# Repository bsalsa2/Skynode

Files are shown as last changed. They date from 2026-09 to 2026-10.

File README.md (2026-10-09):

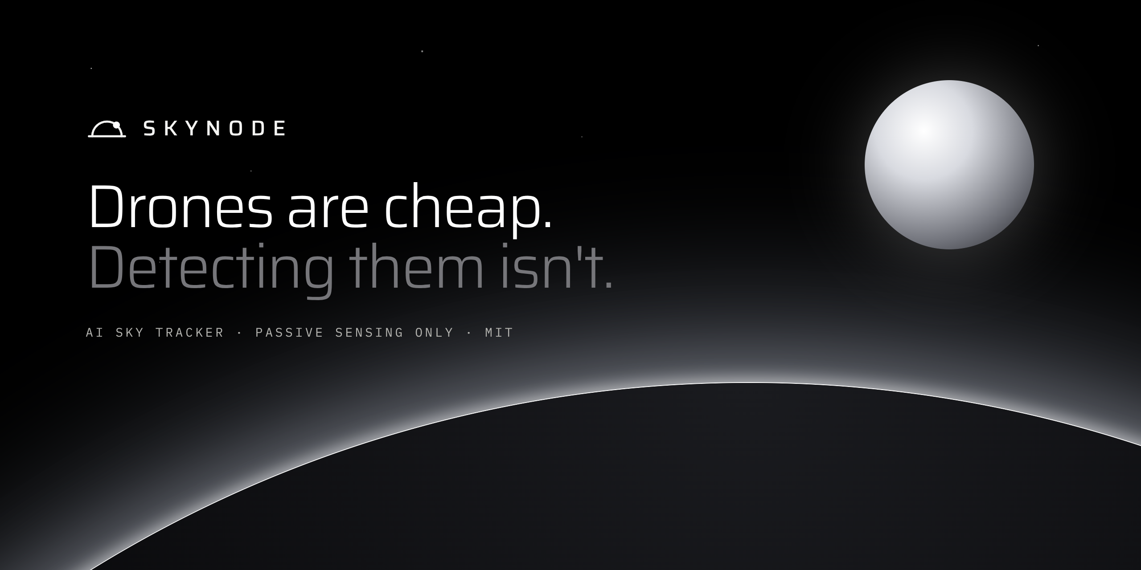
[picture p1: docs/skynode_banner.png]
Skynode: Drones are cheap. Detecting them isn't.


# Skynode

  

**Website: [skynode-si.netlify.app](https://skynode-si.netlify.app)** (source in [`web/`](web/))

**A low-cost visual sensing platform, starting with one passive sky-tracking node.**

A webcam on a pan-tilt mount watches the sky, a YOLO model finds aircraft and birds in each frame, the mount turns to follow the target, and every sighting is logged. This is Phase 1: one node, mostly tested in simulation so far. The physical unit is not built yet.

> **Scope:** passive sensing and tracking only. No payloads, no effectors, and nothing that interacts with or interferes with aircraft. No jamming, no spoofing, and no transmitting on aviation or drone-control frequencies. Ordinary Wi-Fi and USB networking between Skynode's own parts is fine.

## Status

| Part | Status | Notes |
|---|---|---|
| Pico servo firmware (smooth motion, calibration, command protocol) | Tested in software | Not yet run on the physical servos |
| Detection and tracking loop | Simulated | Runs on recorded video and a webcam; covered by the test suite |
| Pan-tilt control | Simulated | Sends commands to the Pico over Wi-Fi or USB |
| Sighting logger | Simulated | Built and tested; not yet run on the real hardware |
| Live dashboard | Simulated | Built and tested; not yet run on the real hardware |
| Pan-tilt mount (CAD) | Designed | STEP and STL files included; not printed |
| Wiring and bill of materials | Designed | Breadboard prototype plan; not wired |
| Detection model v2 | Tested on video | 43 real-world clips (see Results) |
| Detection model v3 (drone and aircraft classes) | In training | Not yet scored |
| Physical build | **Not built yet** | Nothing has run on real hardware |
| Accuracy against ADS-B flight data | Written, not yet run | Logger and comparison tool exist; tested only on made-up data. No results yet |

## How it works

```mermaid
flowchart LR
    CAM[Webcam] -->|frames| DET[Detection<br/>YOLOv8n · ONNX]
    DET -->|boxes| TRK[Tracking<br/>pick one target]
    TRK -->|pixel error| CTL[Pan-tilt control<br/>proportional]
    CTL -->|P92.5 T47.0<br/>Wi-Fi or USB| PICO[Pico WH<br/>servo firmware]
    PICO -->|PWM| SERVOS[Pan + tilt<br/>servos]
    SERVOS -.->|camera moves| CAM
    DET --> LOG[(Sighting logger)]
    TRK --> LOG
    LOG --> DASH[Live dashboard]
```

1. **Detection.** The brain (a laptop for now, a Raspberry Pi 4 later) grabs webcam frames and runs a YOLO model through ONNX Runtime. It runs a custom two-class model (`drone` and `aircraft`). See [Model](#model).
2. **Tracking.** It picks one target and measures how far that target sits from the center of the frame, in pixels.
3. **Pan-tilt control.** A proportional controller turns the pixel error into a small correction ("the target is 40 px right, so pan +2°").
4. **Actuation.** The brain sends a plain-text command like `P92.5 T47.0` to the Pico over Wi-Fi (UDP) or USB serial. The Pico moves both servos smoothly and keeps them inside safe angle limits.
5. **Logging.** Each sighting is recorded with time, class, confidence, pan and tilt angle, and a snapshot. A live dashboard shows the camera, the boxes, and the log as it grows. See [Live dashboard](brain/README.md#live-dashboard).

Detection, tracking, and control are separate modules, so each layer can be reused on future platforms.

## Quickstart

Software only. You can run detection on a webcam or video file without the Pico.

```bash
pip install -r brain/requirements.txt opencv-python-headless onnx pyyaml
python -m unittest discover tests -v      # hardware-dependent tests skip with a stated reason
```

Then follow [`brain/README.md`](brain/README.md) to export the YOLOv8n model once and run the brain.

No hardware? `python -m brain.demo <folder of test videos> --model <model.onnx>` runs detection, the logger and the dashboard on your own videos. See [Demo mode](brain/README.md#demo-mode-your-own-test-videos). For the Pico, see [`pico/README.md`](pico/README.md).

## Results so far

All numbers here come from the repo. Nothing has been measured on the physical node.

**Detection model v2**, tested on **43 real-world videos** of planes, military jets, and drones:

- On real aircraft, v2 wrongly called **7.5% of frames** a drone (**798 of 10,657** frames).
- That was **0.8%** for civilian planes and **10.8%** for military jets (mostly distant F-35s).

**Model v3** (merged classes `drone` and `aircraft`, 960 px input, resumed from v2) is in training. Next step: score it against the same 43 clips.

Training used YOLOv8n on a 28,526-image aircraft and drone dataset. See [Training](training/README.md).

## Known limits

- **Range (estimate, not yet measured).** A wide-lens webcam detects small drones only at short range, likely tens of meters. Aircraft are detectable much farther.
- **Conditions.** Visual sensing is weaker in darkness, fog, and rain.
- **Not a replacement for Remote ID or RF sensors.** It can see drones that broadcast nothing, which Remote ID can't, but it doesn't replace either.
- **Hardware not built.** Nothing has run on the physical servos, camera mount, or Pico yet. Anything marked "simulated" has only been tested in software.

## Repo layout

```
skynode/
├── pico/       MicroPython servo firmware (runs on the Pico WH)
├── brain/      detection, tracking, control, logging (runs on laptop / Pi 4)
├── hardware/   3D-print files for the pan-tilt mount
├── training/   Colab training notebook and dataset scripts
├── web/        project website
├── docs/       wiring diagram, banner, renders
└── tests/      laptop-side tests
```

## Model

Model files are **not** in git (`*.onnx` and `*.pt` are gitignored).

- **Current model: a custom two-class YOLOv8n**, with classes `drone` and `aircraft`. It was built by merging the labels of a source dataset of **28,526 labeled images** into those two classes. Its first version is **v2** (results above).
- **v3** (`drone` and `aircraft`, 960 px input, resumed from v2) is **in training**. It has not been scored yet.
- The model path and target classes are settings in `brain/config.toml`, so a new model drops in without code changes.
- See [Training](training/README.md) for how models are made. Finished models go on [GitHub Releases](https://github.com/bsalsa2/Skynode/releases).

## Bill of materials

Also in [`bom.csv`](bom.csv). Costs are rough USD estimates for the whole line (both servos in the servo row), before shipping.

| Part | Qty | Purpose | Est. cost | Link |
|---|---|---|---|---|
| Raspberry Pi Pico WH | 1 | Servo controller + Wi-Fi link (already owned) | owned | [link](https://www.raspberrypi.com/products/raspberry-pi-pico/) |
| Breadboard | 1 | Power rails and signal wiring (already owned) | owned | |
| SG90 micro servo (or SG92R) | 2 | Pan and tilt axes | $11.90 | [link](https://www.adafruit.com/product/169) |
| SG90 pan-tilt bracket (or print `hardware/pantilt.scad`) | 1 | Holds both servos and the camera | $8.95 | [link](https://www.adafruit.com/product/1968) |
| 1080p USB webcam | 1 | The camera that watches the sky | $70.00 | [link](https://www.logitech.com/en-us/shop/p/c920s-pro-hd-webcam) |
| 5V 2A USB power supply | 1 | Dedicated servo power | $7.95 | [link](https://www.adafruit.com/product/1994) |
| USB breakout board | 1 | Brings the supply's 5V and GND onto the breadboard rails | $1.50 | [link](https://www.adafruit.com/product/1833) |
| 470–1000 µF 16V+ electrolytic capacitor | 1 | Absorbs servo current spikes across the servo power rails | $0.95 | [link](https://www.sparkfun.com/electrolytic-decoupling-capacitors-1000uf-25v.html) |
| Jumper wires (male/male) | 1 | Breadboard and servo connections | $3.95 | [link](https://www.adafruit.com/product/758) |
| M2/M3 screw assortment | 1 | Servo tabs and horns (M2), tilt pivot and base mounting (M3) | $8.00 | |
| Computer that runs the model | 1 | Laptop now, Raspberry Pi 4 later (not in the total) | not included | |
| **Total to buy** | | | **$113.20** | |

About $113 in new parts for the sensing hardware (camera, servos, mount, power), before the computer that runs the model. The total leaves out the Pico WH and breadboard (already owned) and the computer.

## Wiring

Skynode wiring diagram

SG90 wire colors: **brown = GND**, **red = +5 V**, **orange = signal**.

| From | To |
|---|---|
| 5 V 2 A supply → USB breakout VBUS | breadboard + rail |
| USB breakout GND | breadboard − rail |
| Both servo reds | + rail |
| Both servo browns | − rail |
| Pan servo orange | Pico pin 1 (GP0) |
| Tilt servo orange | Pico pin 2 (GP1) |
| Pico pin 3 (GND) | − rail (common ground) |
| 470–1000 µF capacitor | across + and − rails, stripe to − |
| Pico micro-USB | laptop (USB link) or any phone charger (Wi-Fi link) |

**Power notes**

- The servos get their own 5 V 2 A supply, so a stalling servo can't brown out the Pico. Don't also connect Pico VBUS (pin 40) to the + rail, or two supplies will fight.
- The common ground wire is required: servo signals are measured against GND.

## Pan-tilt mount

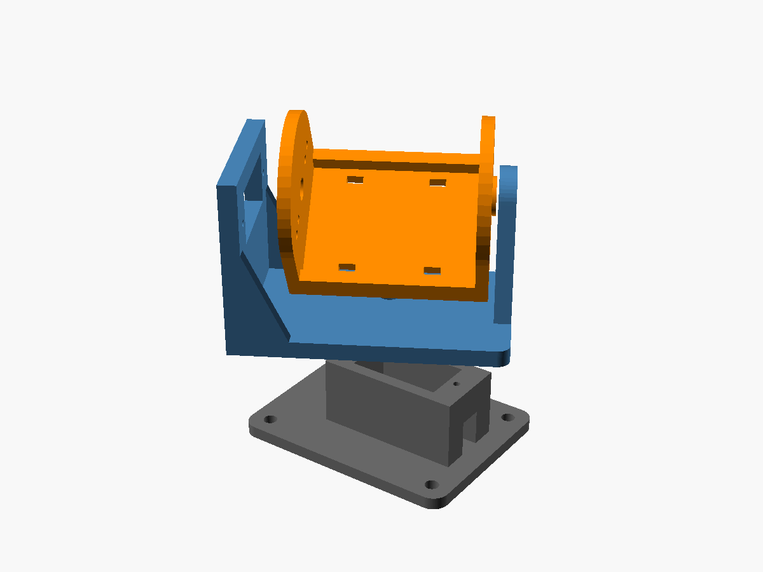
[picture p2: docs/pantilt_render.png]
Pan-tilt mount render


[`hardware/pantilt.py`](hardware/pantilt.py) is a parametric CadQuery design: servo size, horn, webcam size, and wall thickness are parameters at the top of the file. Each part has an editable STEP file and a print-ready STL. It prints as three parts without supports:

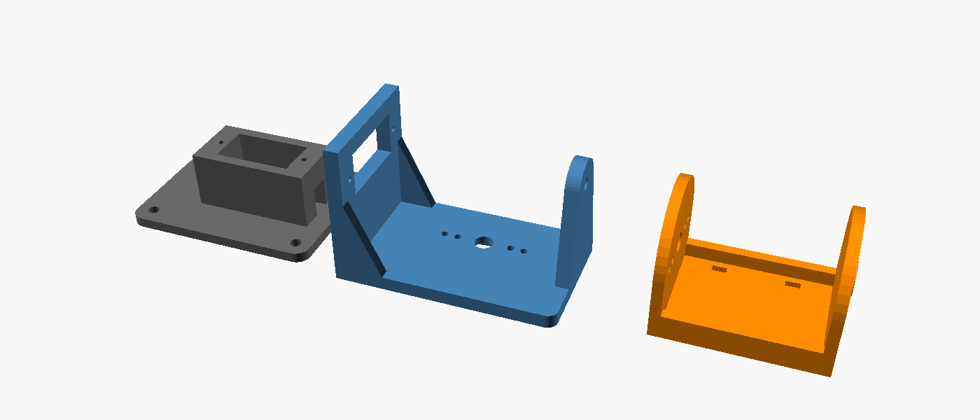
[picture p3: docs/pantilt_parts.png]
The three printed parts


| File | Part |
|---|---|
| [`pantilt_base.step`](hardware/pantilt_base.step) · [`.stl`](hardware/pantilt_base.stl) | Holds the pan servo; screws down with 4× M3 |
| [`pantilt_yoke.step`](hardware/pantilt_yoke.step) · [`.stl`](hardware/pantilt_yoke.stl) | Sits on the pan horn; holds the tilt servo and the M3 pivot |
| [`pantilt_camera_arm.step`](hardware/pantilt_camera_arm.step) · [`.stl`](hardware/pantilt_camera_arm.stl) | Webcam cradle on the tilt horn; camera held with two zip ties |

Measure your servo and camera and adjust the parameters before printing. See [`hardware/README.md`](hardware/README.md).

## Roadmap

**Vision.** Phase 1 is one passive sky-tracking node. The long-term goal is autonomy for missile and drone detection and defense systems. Open work is tracked as [GitHub issues](https://github.com/bsalsa2/Skynode/issues) under the *Phase 1: one working node* milestone.

- [x] Pico servo firmware: smooth motion, calibration, command protocol (tested in software)
- [x] Detection and tracking loop, working in simulation, covered by automated tests
- [x] Pan-tilt mount designed in CAD, with STEP and STL files
- [x] Wiring diagram and bill of materials
- [ ] Detection model training: v3 with drone and aircraft classes (in training, not yet scored)
- [ ] Sighting logger (built and tested in simulation; not yet run on real hardware)
- [ ] Live dashboard (built and tested in simulation; not yet run on real hardware)
- [ ] Build the physical hardware
- [ ] Outdoor test
- [ ] Test against real flight data (ADS-B) and publish accuracy results
- [ ] Pi 4 + solar deployment

**Nothing has run on real hardware yet.** Every item marked as simulated or software-tested has only been checked on a computer.

The website's Status section lists these same items. Update both together.

## Built with Claude Code

Claude Code (Anthropic's coding agent) helped write much of the code, tests, and documentation here. Every change is in the git history.

## License

MIT, see [LICENSE](LICENSE).

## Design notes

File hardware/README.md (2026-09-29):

# hardware/

Parametric pan-tilt mount for two SG90 servos and a small USB webcam.

**Source of truth: [`pantilt.py`](pantilt.py) (CadQuery).** It builds every printed part as an editable STEP file plus an STL. [`pantilt.scad`](pantilt.scad) is the original OpenSCAD version, kept for reference: same parameters and identical geometry, but edit the CadQuery script first, and copy any change to the SCAD file only if you still use it.

| File | What it is |
|---|---|
| `pantilt.py` | The design (CadQuery). All dimensions are parameters at the top |
| `pantilt.scad` | Original OpenSCAD version (reference only) |
| `pantilt_base.step` / `.stl` | Base: holds the pan servo (shaft up) and screws down with 4× M3 |
| `pantilt_yoke.step` / `.stl` | Yoke: sits on the pan horn, holds the tilt servo, carries the M3 pivot |
| `pantilt_camera_arm.step` / `.stl` | Camera arm: webcam cradle on the tilt horn and pivot. Strap the camera with two zip ties |

A two-axis mount needs three moving links (fixed, panning, tilting), so it prints as three parts.

## Before printing

Measure your servo and camera with calipers and edit the parameters: `servo_l/w/h`, `tab_z`, `horn_seat_z`, the horn sizes, and `cam_w/h/d`. Then rebuild all STEP and STL files from the repo root:

```
pip install cadquery
python hardware/pantilt.py
```

The STEP files open in FreeCAD, Fusion 360, Onshape, or SolidWorks for further editing.

Print in PLA or PETG, 0.2 mm layers, 3 walls, 25–40 % infill, no supports. The parts are already oriented flat side down.

## Assembly

1. **Base:** drop the pan servo into the base, with its lead through a cable slot, and screw the tabs down (M2 self-tapping; SG90s come with these).
2. **Yoke:** press a double-arm horn into the recess under the yoke and fix it with two M2 screws from the top. Center the pan servo (`HOME`, 90°), set the yoke facing forward, press the horn onto the spline, and drive the horn screw through the center hole.
3. **Tilt servo:** push it through the yoke's window from the outside, shaft pointing in, and screw its tabs to the upright.
4. **Camera arm:** fix a horn into the left cheek's recess, put the arm between the uprights, press the horn onto the tilt servo (servo at its level angle), and add the horn screw. On the other side, an M3 × 12 screw with a washer goes through the yoke's pivot hole into the arm.
5. Zip-tie the webcam into the cradle, lens forward.

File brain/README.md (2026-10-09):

# brain/

Runs on the laptop now and on a Raspberry Pi 4 later. Every camera frame goes through four steps: **detect → track → control → send**.

| Module | Job |
|---|---|
| `detector.py` | Runs a YOLO model (ONNX) on a frame and returns detections: class, confidence, box |
| `tracker.py` | Picks one target and stays locked on it from frame to frame |
| `controller.py` | Proportional control: how far off-center the target is → new pan/tilt angles |
| `link.py` | Talks to the Pico over Wi-Fi (UDP), USB serial, or not at all |
| `overlay.py` | Draws boxes and status on the preview window |
| `logger.py` | Logs every sighting (plus an hourly "sky clear" check) to `logs/`, with a snapshot of its best moment |
| `dashboard.py` | The live dashboard: a small web server inside the brain, for your browser |
| `dashboard/` | The dashboard page itself: HTML, CSS, JavaScript and fonts, all served locally |
| `config.py` + `config.toml` | Settings: defaults in code, your changes in the TOML file |
| `run.py` | The main loop that wires it all together |

An ADS-B logger and comparison tool are written (see "Compare with real flights" below) but have not yet been run against a real feed.

## Setup

You need Python **3.11 or newer**. From the repo root:

```
python -m venv .venv
.venv\Scripts\activate            # Windows
source .venv/bin/activate         # Mac / Linux
pip install -r brain/requirements.txt
```

## Get a model

Start with the pretrained **YOLOv8n** COCO model. It has 80 everyday classes, including `airplane` and `bird`. Export it to ONNX once:

**Option A: Google Colab** (nothing to install locally). In a new notebook, run:

```
!pip install ultralytics
!yolo export model=yolov8n.pt format=onnx
from google.colab import files; files.download("yolov8n.onnx")
```

**Option B: locally**, with `pip install ultralytics` and then `yolo export model=yolov8n.pt format=onnx`. Ultralytics pulls in PyTorch, which is a big download, and you only need it for this one step.

Save the file as **`brain/models/yolov8n.onnx`**. YOLO11 and YOLO26 exports work too (`model=yolo11n.pt`); just change `path` in `config.toml`.

## Run it

### 1. Detection only, no Pico needed

```
python -m brain.run
```

A preview window opens with the webcam. Hold up your phone showing a photo of an airplane or a bird. Target-class detections get a **yellow** box, and the locked target turns **green**. Press `q` to quit. To test on footage instead, use `--source planes.mp4`.

While it runs, open **http://localhost:8080/** in your browser for the [live dashboard](#live-dashboard).

### 2. With the Pico

- **Wi-Fi:** set up the Pico's Wi-Fi (see [`pico/README.md`](../pico/README.md#5-wi-fi-optional)), then run `python -m brain.run --link wifi`. The brain finds the Pico automatically. To make Wi-Fi the default, set `type = "wifi"` under `[link]` in `config.toml`.
- **USB:** close Thonny, then run `python -m brain.run --link usb`.

When it connects, the brain reads the Pico's angle limits, home, and current position. That way both sides agree on where the camera is pointing.

### 3. First aiming test

1. With the camera on the pan-tilt mount, hold the airplane photo off to the **right** of the camera's view. The camera should turn right, toward it, and settle with the target near the center cross.
2. If it turns **away**, flip `pan_sign` in `config.toml` (`-1` ↔ `1`). Test tilt the same way, holding the photo above the camera and flipping `tilt_sign` if needed.
3. If it overshoots and wobbles, lower `gain` (try 0.2). If it's sluggish, raise `gain` (up to about 0.5) or raise `SPEED` on the Pico.
4. Set `hfov_deg` to your webcam's field of view, so that "20 pixels off-center" turns into the right number of degrees.

## Live dashboard

While the brain runs, open **http://localhost:8080/** in a browser on the same computer. The brain prints the address when it starts:

```
Logging sightings to C:\Users\you\Skynode\logs
Dashboard: http://localhost:8080/
```

The page comes from the brain itself: no internet, no cloud, no account. It has four tabs:

- **Overview:** the live camera with a box around everything the model sees (the locked target gets a solid label), plus pan, tilt and frames per second. Next to it: sightings, drones and aircraft over the last 24 hours, the most recent sightings, and a chart of sightings by hour.
- **Sightings:** the whole log as cards with snapshots. Filter by time (24 hours, 7 days, all) and category (drone, aircraft, other, sky checks). Click a sighting to see all its details.
- **Nodes:** this node's status: online or offline, uptime, how much of that time the camera was actually watching, and which model, camera and link it uses.
- **Settings:** the settings the brain is running with, read-only. To change them, edit `config.toml` and restart the brain.

The dashboard's settings are under `[dashboard]` in `config.toml`. For one run on another port: `python -m brain.run --port 8081`. Without the dashboard: `--no-dashboard` (or `enabled = false`). The logger keeps working either way.

### Demo mode: your own test videos

No Pico, no camera, no real node yet? Run the whole thing (detector, tracker, logger and dashboard) on a folder of videos:

```
python -m brain.demo C:\Users\you\skynode-videos --model models\your-model.onnx --classes drone,aircraft
```

Then open the dashboard as usual. The videos play one after another, in file-name order, and everything on the dashboard comes from this run:

- It's the same code as `python -m brain.run`. Only the camera is different.
- The dashboard says **DEMO · TEST VIDEOS** at the top, because it isn't a live camera.
- There's no Pico, so **pan and tilt are simulated** from where the target is in the picture: the angles the camera *would* point at to center it.
- It logs to `logs/demo/`, apart from your real log, and **starts that log afresh every time**. Add `--keep-logs` to keep the last demo's sightings.
- Time in the demo is the video's time. A 4-second clip is a 4-second sighting, even with `--fast`.

Options: `--classes` (the model's class names to track, like `drone,aircraft`; the default is `target_classes` in `config.toml`), `--fast` (don't wait for each video's own speed), `--loop` (play the folder again and again), `--port`, `--show` (also open the preview window), and `--exit-when-done` (quit after one pass instead of keeping the dashboard open).

**Keep the videos outside the repo folder.** They're never copied or changed, and the demo refuses a folder inside the repo that git doesn't ignore, so they can't be committed by accident. (`demo_videos/`, `test_videos/` and `videos/` in the repo folder are ignored.) The demo only looks at video files directly in the folder you give it (`.mp4 .mov .m4v .avi .mkv .webm`), not in sub-folders.

### What counts as a sighting

A sighting is one continuous lock: from the frame the tracker locks on to the frame it gives up (after `max_missed_frames` frames without seeing the target). Locks shorter than `min_duration_s` (half a second) are most likely the detector blinking, so they aren't logged. For each sighting the log keeps when it started and ended, what the model called it, its best confidence, where the camera pointed at that best moment, and a snapshot of that frame. The terminal shows each one as it's saved:

```
LOGGED airplane 4.2s peak 0.91
```

The model's class decides the category: names in `drone_classes` are **drone**, names in `aircraft_classes` are **aircraft**, and anything else is **other**. With the COCO model that means `bird` sightings are filed under *other*, even though small drones often show up as birds. A custom drone model fixes that.

While nothing is being tracked, the logger also writes a **sky check** once an hour, on the hour (`heartbeat_min = 60`). It proves the node was watching and saw nothing, so a gap in the log means "the brain wasn't running", not "empty sky".

### Where the logs go

```
logs/skynode.db                          every sighting and sky check (SQLite)
logs/snapshots/20261007-140217-001.jpg   the best frame of that sighting
```

`logs/` sits in the repo folder, and git ignores it, so your sightings never end up on GitHub. `skynode.db` is one ordinary SQLite file, and each record is committed the moment a sighting ends, so a crash or a power cut loses nothing that was already logged. The dashboard shows the last 7 days; older sightings stay in the database. To start fresh, delete the folder while the brain isn't running.

To look at it yourself, open it with any SQLite tool (DB Browser for SQLite, or `sqlite3 logs/skynode.db`). One row per sighting or sky check, in a table called `sightings`; `started` and `ended` are unix times in seconds:

```
sqlite3 logs/skynode.db "SELECT id, category, class_name, confidence FROM sightings WHERE kind = 'sighting' ORDER BY started DESC LIMIT 5"
```

Earlier versions wrote one `sightings-YYYY-MM-DD.jsonl` file per day. If you have those, they're imported into the database the first time you start the brain, then renamed to `.jsonl.imported`.

### Export a spreadsheet (to compare with ADS-B)

On the **Sightings** tab, pick a time range and a category, then click **Export CSV**. You get `skynode-sightings.csv`, one row per sighting, newest first:

```
id,kind,category,class_name,start_iso,end_iso,duration_s,confidence,pan,tilt,frames,snapshot
```

`start_iso` and `end_iso` are your local time with its offset from UTC, like `2026-10-07T14:02:17+02:00`. ADS-B flight data is usually in UTC, and the offset makes the conversion exact. Line the times up, then use `pan` and `tilt` to check that the aircraft was where the camera pointed. The export covers what the dashboard shows (the last 7 days, up to 10,000 rows); for anything older, query `logs/skynode.db`.

### Compare with real flights (ADS-B)

Planes broadcast their position, and free public feeds (adsb.lol, airplanes.live) share it with no account. The feeds only show what is flying *now*, so a small logger has to run next to the brain and write it down:

```
python -m brain.adsb             # leave it running while the brain runs
python -m brain.adsb_compare     # afterwards: which sightings does the flight record explain?
```

**Tell it where the camera is, without putting your home on GitHub.** Set `SKYNODE_LAT`, `SKYNODE_LON` (and optionally `SKYNODE_ALT_M`), or create `brain/location.local.toml` with `lat = ...`, `lon = ...`, `alt_m = ...`. Git ignores that file, and the location is never read from `config.toml`. By default the request to the feed uses your position rounded to about 1 km, with a slightly larger radius, and the exact distances are worked out on your computer. Add `--exact` to send the precise position instead.

It writes `logs/adsb_log.csv` (every aircraft within 25 km, with its azimuth and elevation in your sky) and `logs/adsb_polls.csv` (each time the feed answered). The second file is what tells "no aircraft overhead" from "the logger wasn't running". Those sightings are reported as `no_data` and left out of every percentage.

`adsb_compare` reports how many aircraft sightings had a real flight nearby, and how many drone sightings did (possible misclassifications). Two honest limits: it means an aircraft was *nearby*, not that the camera was pointed at it, and planes without a transponder, such as gliders and most drones, never show up. It measures agreement with the public flight record, not accuracy. Treat each mismatch as a lead to check in the snapshot.

### Open it from your phone

By default only the computer running the brain can open the dashboard. To open it from a phone or another laptop on the same Wi-Fi:

1. Set `host = "0.0.0.0"` under `[dashboard]` in `config.toml`, then restart the brain.
2. Find the computer's IP address. Windows: run `ipconfig` and look for *IPv4 Address*. Mac: System Settings → Wi-Fi → Details. Linux or the Pi: `hostname -I`.
3. On the phone, open `http://<that address>:8080/`, for example `http://192.168.1.42:8080/`.

> **Privacy warning:** with `host = "0.0.0.0"`, **anyone on the same network can open the dashboard and watch your camera. There is no password.** Only do this on your own home network, never on school, café or other public Wi-Fi, and set it back to `"127.0.0.1"` when you're done. Point the camera at the sky, not at the neighbours' windows.

On Windows, the firewall may block the phone. Allow Python through it for **Private** networks, the same as for the Pico's Wi-Fi link.

Other web sites can't use the dashboard, even while you have it open. A page somewhere else can't show your camera inside itself, peek at your snapshots, or take up the live stream's places (there are 4). The brain only answers the dashboard's own page, an address you type in or bookmark, and plain links to its front page.

### Try it in the cloud (GitHub Codespaces)

No install and nothing stored on your own computer. A Codespace is a computer GitHub runs for you, and the dashboard opens in a browser tab. It uses a video file as the camera (a cloud computer has no webcam).

1. Download two files to your device: the model `skynode-v3-<date>.onnx` (from Drive ▸ skynode ▸ models) and one short video of a plane or drone.
2. On github.com open the repo, use the branch menu to pick the branch you want, then **Code ▸ Codespaces ▸ Create codespace**. Wait about 2 minutes: `.devcontainer/devcontainer.json` installs the packages for you.
3. In the file list on the left, drag the `.onnx` into `brain/models/` and the video into the top folder (call it `clip.mp4`).
4. Open the terminal (Terminal ▸ New Terminal) and run:
   ```
   python -m brain.run --config brain/config.v3.toml --source clip.mp4 --loop
   ```
   If your model file has a different name, edit `path` in `brain/config.v3.toml`.
5. When it prints `In GitHub Codespaces, open https://...`, click that link (or open the **Ports** tab and click the globe next to port 8080).
6. Press Ctrl+C in the terminal to stop. **Stop the Codespace** when you're done (github.com/codespaces ▸ the `...` menu ▸ Stop). It also stops itself after a while, and the free monthly allowance is limited.

How it stays safe: the dashboard answers only your own Codespace's address, not the rest of `app.github.dev`. Codespaces ports are private (you must be signed in to GitHub) unless you change them to Public, so **don't make port 8080 public**.

Not verified: the live camera picture goes through GitHub's proxy, and I couldn't test how it handles a continuous stream. If the picture stalls, the stat tiles, sightings and chart still work.

## Swap in your own model

No local GPU? Train in Google Colab with phone videos: see [`training/`](../training/README.md).

1. Train with Ultralytics (YOLOv8, YOLO11, or YOLO26), then export: `yolo export model=best.pt format=onnx`.
2. Copy the `.onnx` file into `brain/models/` and update `config.toml`:
   ```toml
   [model]
   path = "models/skynode-drone.onnx"
   target_classes = ["drone", "airplane", "helicopter"]
   ```
3. That's it. The class names are stored inside the `.onnx` file. If a target class isn't in the model, the brain stops and lists the classes the model does know.

Exports made with `nms=True` work too.

## What to expect from the COCO model

- **COCO has no `drone` or `helicopter` class.** Small drones tend to show up as `bird` (sometimes `airplane` or `kite`), which is why `bird` is a default target. It's also the main reason to train your own model.
- **Real birds will trigger it too.** That's the cost of using a stand-in class.
- **Small targets are hard.** A distant aircraft may be only a few pixels wide once the frame is shrunk to 640 × 640. A narrower camera lens (zoom) gains more range than a bigger model does.
- **On a Pi 4**, export with `imgsz=320`. That's roughly 4× faster than 640, at the cost of detection range.

## License note

Ultralytics YOLO weights and anything exported from them are licensed **AGPL-3.0**. Skynode's code never imports Ultralytics (it runs the exported file with ONNX Runtime), but the model file itself comes under Ultralytics' license. That's fine for a personal or open-source project. For a commercial product, plan on either an Ultralytics Enterprise license or training an Apache-2.0 detector (such as YOLOX or RT-DETR) on your own dataset.

## Troubleshooting

| Message or symptom | Fix |
|---|---|
| `No Pico answered on UDP port 5005` | Make sure the Pico shows `WIFI up` and is on the same network. On Windows, allow Python through the firewall for **Private** networks and set your Wi-Fi's network profile to Private. Or set `wifi_host` to the IP address the Pico printed |
| `No Pico found on USB` | Some USB cables only carry power; use a data cable |
| `Can't open COM…` / `/dev/ttyACM0` | Thonny is holding the port; close it |
| `Can't open camera` | Another app (Zoom, Teams, …) has the webcam. For a second camera, use `source = 1` |
| Camera swings away from the target | Flip `pan_sign` or `tilt_sign` |
| Camera wobbles around the target | Lower `gain` |
| `Target class(es) … aren't in this model` | Check the spelling. The message lists every class the model knows |
| Pan/tilt run to their limits when testing on a video file | Expected: a video can't move, so the target never gets centered |
| `WARN the dashboard can't start on 127.0.0.1:8080` | Another program (or a second copy of the brain) is using port 8080. Run with `--port 8081`, or change `port` in `config.toml`. Tracking and logging keep going without the dashboard |
| The dashboard says OFFLINE | The brain isn't running, or the camera stopped sending frames. Check the terminal |
| The phone can't open the dashboard | Set `host = "0.0.0.0"`, use the computer's IP address (not `localhost`), and stay on the same Wi-Fi. On Windows, allow Python through the firewall for Private networks |
| `403`: *Open the dashboard by this computer's address* | You opened it by a name with a real domain, like a custom DNS name `skynode.example.com`. To block a trick called DNS rebinding, the dashboard only answers to `localhost`, an IP address (`http://192.168.1.42:8080/`), the computer's plain name (`raspberrypi`) or a home-network name like `raspberrypi.local`. Use one of those, or list the one exact name you trust in `allowed_hosts` in `config.toml` (GitHub Codespaces addresses are added for you) |
| `403`: *Only the dashboard's own page can load this* | Another web site (or another app on this computer) tried to load the camera or the log. That's blocked on purpose. Open the dashboard itself, e.g. `http://localhost:8080/` |

## Tests

```
python -m unittest discover tests
```

The detector tests build tiny fake models, which needs one extra package: `pip install onnx`. Without it they're skipped. The demo tests make their own tiny videos, and need numpy, OpenCV and onnxruntime (the same as running the brain).

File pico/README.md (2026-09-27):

# pico/: servo firmware

MicroPython firmware for the Raspberry Pi Pico WH. It listens for text commands over USB serial and, optionally, Wi-Fi, and drives the **pan (GP0)** and **tilt (GP1)** servos. Motion is smooth and speed-limited, and angles stay inside calibrated limits.

| File | Job |
|---|---|
| `main.py` | Entry point, runs at power-up. A 50 Hz loop: read USB and Wi-Fi, run commands, step servos |
| `pantilt.py` | The two-servo mount: runs commands, loads/saves `config.json` |
| `servo.py` | One servo: pulse calibration, angle limits, smooth motion |
| `protocol.py` | Parses command text. No hardware code, so it runs on a laptop too |
| `wifi.py` | Optional Wi-Fi link: joins your network, receives commands over UDP |
| `wifi_secrets_example.py` | Template for `wifi_secrets.py` (your network name and password) |

## 1. Flash MicroPython (once)

1. Download the latest **Pico W** `.uf2` from <https://micropython.org/download/RPI_PICO_W/>. The WH is a Pico W with headers, so it takes the same firmware. Any version from 1.20 on works.
2. Hold the **BOOTSEL** button, plug the Pico into USB, then release. A drive called `RPI-RP2` appears.
3. Drag the `.uf2` onto that drive. The Pico reboots into MicroPython.

Any laptop works for this. If your main laptop's USB ports are unreliable, do it from the second one.

## 2. Copy the firmware onto the Pico

**Thonny:** in the bottom-right corner, pick *MicroPython (Raspberry Pi Pico)*. Open `servo.py`, `protocol.py`, `pantilt.py`, `wifi.py`, and `main.py`, choose *File → Save as… → Raspberry Pi Pico*, and keep the same name. Save `main.py` last.

**Or from the command line** (from the repo root):

```
pip install mpremote
mpremote cp pico/servo.py pico/protocol.py pico/pantilt.py pico/wifi.py pico/main.py :
mpremote reset
```

## 3. Test it

Wire the servos first (see the [top-level README](../README.md#wiring)). In Thonny, open `main.py` **from the Pico** and press Run (F5). The Shell prints `READY skynode-pico`. Then type:

```
?              → POS P90.0 T45.0
P0             pan swings to 0°
P180           …and across to 180°
T90            tilt to 90°
P90 T45        both at once
SPEED 30       slow down, then try P0 again
HOME           back to P90 T45
```

Moves print nothing on purpose (see the [protocol](#command-protocol)). Use `?` to see where the servos are.

## 4. Calibrate (about 10 minutes, once per servo)

Every SG90 is a little different. Uncalibrated, "90°" might really be 84°, and each sighting logs these angles, so the log is only as accurate as this step.

Print any free paper protractor and center it under the servo horn.

1. `RAW P 1500` puts the servo roughly at center. Push the horn on so it points at 90°.
2. Lower the pulse step by step (`RAW P 1000`, `RAW P 700`, `RAW P 600`, …) until the horn points at **0°**, and note the number. If the servo **buzzes or stops moving** before it reaches 0°, it has hit its internal end stop. Back off about 30 µs and use that value.
3. Do the same upward for **180°** (`RAW P 2000`, `RAW P 2300`, …).
4. Enter both values, for example `CAL P 540 2380`. Check that `P0`, `P90`, and `P180` now land on the marks.
5. Repeat steps 1–4 for tilt, using `T` instead of `P`.
6. Once the servos are in the bracket, find any angle where parts bind or cables pull, and fence it off. For example, `LIM T 0 100` keeps tilt between 0° and 100°.
7. `SAVE` writes `config.json` to the Pico, and it loads at every boot. `CFG` prints the current settings.

To start over, delete `config.json` in Thonny's file panel (*View → Files*) and reset the Pico.

## 5. Wi-Fi (optional)

With Wi-Fi set up, the Pico only needs power: a phone charger or power bank will do. The brain talks to it over your network, so the laptop's USB ports don't matter. USB serial keeps working as well.

1. Copy `wifi_secrets_example.py` to `wifi_secrets.py` and fill in your network name and password. It is gitignored, so it stays off GitHub.
2. Save it to the Pico as `wifi_secrets.py`, then reset the Pico or press Run in Thonny.
3. Within a few seconds the Shell prints `WIFI up 192.168.1.42 port 5005` (with your Pico's IP address).

The brain finds the Pico automatically: it broadcasts `?` on the local network and the Pico answers. If that's blocked on your network, put the IP address in the brain config. Most routers also let you "reserve" an IP address for a device so it never changes.

While Wi-Fi is down, the firmware retries every 15 seconds and prints `WIFI retry (last status N)`:

| Status | Meaning |
|---|---|
| -3 | Wrong password |
| -2 | Network not found. Check the name, and make sure it's a 2.4 GHz network |
| -1 | Connection failed, often a weak signal |
| 2 | Joined, but no IP address from the router yet |

**Security:** anyone on the same network can send the Pico commands. That's fine on your home Wi-Fi, but don't join it to a shared or public network.

## Command protocol

The same commands work over USB and Wi-Fi. **Over USB**, send one command per line, ended by `\n` or `\r\n`. **Over Wi-Fi**, send UDP datagrams to port 5005, each holding one or more lines; replies go back to the sender's address and port. Either way, commands are case-insensitive, with at most 64 characters per line. Replies end with a newline (`\r\n` over USB, `\n` over Wi-Fi), so strip it. At boot the Pico prints `READY skynode-pico`.

| Command | Example | Reply | Notes |
|---|---|---|---|
| `P<deg> T<deg>` | `P92.5 T47` | none | Either axis alone is fine. Out-of-limit values are clamped |
| `HOME` or `H` | | none | Home is pan 90°, tilt 45° (edit in `config.json`) |
| `?` or `STATUS` | | `POS P92.5 T47.0` | Current angles, which trail the target while moving |
| `SPEED <deg/s>` | `SPEED 120` | `OK` | 1–600, default 120 |
| `CAL <P\|T> <min_us> <max_us>` | `CAL P 540 2380` | `OK` | Pulse widths at 0° and 180°, each 400–2600 |
| `LIM <P\|T> <min_deg> <max_deg>` | `LIM T 0 100` | `OK` | 0–180 |
| `RAW <P\|T> <us>` | `RAW P 1500` | `OK` | Calibration only. The next move first snaps back to the last angle, then slews |
| `OFF` | | `OK` | Servos go limp. Any move wakes them |
| `CFG` | | `CFG {…}` | Current settings as JSON |
| `SAVE` | | `OK saved` | Stores settings in `config.json` |
| anything malformed | `P9x` | `ERR <reason>` | |

**Notes for the brain side:**

- Moves are silent, so the brain can stream them at camera frame rate without waiting for acknowledgements. Send `?` when you need the real position.
- Opening the serial port does **not** reboot the Pico (an Arduino does), so you will usually miss `READY`. Send `?` to check that it's alive.
- Only one program can hold the USB serial port at a time. **Close Thonny before running the brain over USB.** Over Wi-Fi, Thonny can stay open, which is handy for watching status lines.

## Troubleshooting

| Symptom | Likely cause |
|---|---|
| Pico disconnects or resets when servos move | The 5 V rail is browning out. Add the capacitor, or use a separate supply (see the power notes in the top README) |
| Servo buzzes at one end | It's pushing against its end stop. Recalibrate (step 4) or tighten `LIM` |
| Servo jitters while idle | Noisy power or a loose ground wire. `OFF` also silences it |
| `WARN bad config.json, using defaults` at boot | The saved file has invalid values. Recalibrate, then `SAVE` |
| `WIFI retry …` keeps repeating | See the status table in [Wi-Fi](#5-wi-fi-optional) |
| `WARN Wi-Fi off: …` at boot | Wi-Fi couldn't start. USB still works. The message says why |
| Typing in Thonny does nothing | `main.py` isn't running (the Shell shows `>>>` instead of `READY`). Press Run |

## Tests (on the laptop)

The firmware logic is tested with regular Python and a fake `machine` module, so no Pico is needed:

```
python -m unittest discover tests
```

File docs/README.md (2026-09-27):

# docs/

Wiring diagrams, build photos, and demo GIFs. Keep images small (under about 2 MB each) so the repo stays fast to clone.

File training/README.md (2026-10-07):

# training/

Train Skynode's own aircraft and drone detector in **Google Colab**, using videos you film on your phone. Everything heavy happens on Google's computers: nothing is stored or run on your laptop.

| File | What it is |
|---|---|
| `skynode_train.ipynb` | The Colab notebook. Open it in Colab and run the cells top to bottom |
| `skynode_v4_export_and_phone_finetune.ipynb` | Fits the existing `skynode/` Drive folder: export v3, then fine-tune on phone video |
| `skynode_data.py` | The bookkeeping the notebook uses (frames, labels, the train/validation split, the dataset folder). Tested in `tests/test_training_data.py` |

## Automatic: `skynode_auto_train.ipynb` (start here)

One notebook, one Run. Put clips in **phone_videos**, run it, and it retrains on only the new clips. It replaces the model only when the new one scores at least as well. Full details are in the notebook. The logic lives in `training/auto_train.py` and is tested in `tests/test_auto_train.py`.

## If you already have a trained model: `skynode_v4_export_and_phone_finetune.ipynb`

This is the notebook that matches the existing `skynode/` Drive folder (classes `drone` and `aircraft`, 960 px, `drone_v3/weights/best.pt`). It leaves the v3 notebook and run untouched and:

1. **exports v3 to ONNX** for `brain/detector.py` (a 2-minute job, runs on its own);
2. scores v3 on your phone videos (false-drone rate on aircraft clips and so on);
3. uses v3 itself to draw first-guess boxes, which you check on contact sheets;
4. fine-tunes v3 into **v4** with the backbone frozen, mixing in a sample of the Roboflow dataset so it doesn't forget;
5. compares v3 and v4 on phone clips the model never trained on, then exports v4.

Put clips in **Drive ▸ skynode ▸ phone_videos**, named `drone_*.mp4`, `aircraft_*.mp4` or `sky_*.mp4`. Your Roboflow key stays in Colab's Secrets (`ROBOFLOW_API_KEY`), never in a cell.

`skynode_train.ipynb` below is the from-scratch version for a fresh Drive.

## Quick start

1. Upload your phone videos to Google Drive in **My Drive ▸ skynode ▸ videos**.
   Name a video after what it shows when it shows only one thing: `drone_garden.mp4`, `airplane_morning.mp4`. The word before the first `_` tells the notebook to keep only that class's boxes. Mixed or empty-sky clips can have any other name (`sky_clear.mp4`).
2. Open `skynode_train.ipynb` in Colab (on GitHub, open the file and use the Colab link, or go to colab.research.google.com ▸ GitHub and paste the repo address). Set **Runtime ▸ Change runtime type ▸ T4 GPU**.
3. Run the cells in order. At the end you get an `.onnx` file in **Drive ▸ skynode ▸ models** (it also downloads).
4. Copy it to `brain/models/`, set `[model] path` and `target_classes` in `brain/config.toml` (the last cell prints the exact lines), and test on a video the model never saw: `python -m brain.run --source some_video.mp4`.

## How it works, and where it can go wrong

1. **Frames:** about one per second of video, shrunk to at most 1280 px on the long side.
2. **First-guess labels:** a ready-made COCO model draws boxes for planes and birds; YOLO-World, which finds things by name, tries for drones. These are guesses.
3. **You check the labels.** The notebook shows contact sheets with numbered boxes; you list frames to `DROP` or `WIPE`. Auto-labels can miss small, distant drones, and a missing box on a real drone teaches the model to ignore drones. This step decides how good the result is.
4. **Honest grading:** with two or more videos, whole videos are held back for validation. Frames from one video are near-duplicates, so mixing them would make the score look better than the real world will be. With a single video, the last 20% is held back.
5. **Train** a small YOLOv8n starting from the COCO weights, saving a checkpoint to Drive every epoch. If Colab disconnects, run the cells again and training resumes.
6. **Export** to ONNX in the same format `brain/detector.py` already reads (class names are stored in the file).

The notebook warns you before training if a class has no (or very few) boxes, or if validation is too small to trust. Heed those: with only 2 or 3 videos the split can leave a class entirely on one side.

## What the scores mean

`mAP50` is measured on your held-out footage, so it describes how the model does on *your* kind of sky. It is not a general accuracy figure. To publish accuracy numbers, compare logged sightings against ADS-B flight data (see `brain/README.md`) rather than quoting this score.

## Adding an older dataset

If you already have a labeled YOLO dataset (an `images/` and `labels/` folder plus a `data.yaml` with class names), put it in Drive and set `EXISTING_DATASET` in the Settings cell. Classes are matched **by name**, so differently numbered datasets merge correctly, and classes you don't use are ignored.

## Limits to know about

- Colab's free GPU time is limited and sessions end after a while. The notebook saves to Drive for this reason.
- Videos still syncing to Drive from your phone can look empty or cut short. Wait until the upload finishes.
- YOLO-World may be slow to download the first time.
- I wrote and tested the notebook's bookkeeping on a laptop, but the GPU cells (auto-labeling, training, export) had not been run in Colab when this was written. If a cell errors, the error message is the thing to bring back.

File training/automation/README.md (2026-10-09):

# Automatic training (free)

Drop a phone clip into your Google Drive and, within about half an hour, a free Kaggle GPU trains on it and the result appears as a GitHub pre-release. Nothing runs on your computer. Everything here is on a free tier (GitHub Actions on a public repo, a Kaggle notebook, a Google service account).

```
Drive clip folders ──read-only──▶ GitHub Actions (every 30 min) ──▶ private Kaggle dataset
                                                                          │
GitHub pre-release  ◀── model + report ◀── Kaggle free GPU trains ◀───────┘
```

**It never changes your node.** A trained model is published as a *pre-release*. You copy the `.onnx` file across yourself, after looking at the report.

**Read this before trusting a result.** Unattended runs label the clips with the *old* model's own guesses and then score the new model against those same guesses (see `auto_train.py`). A new model is only kept if it is no worse than the old one by that test, which is cautious, but it can't catch a mistake the old model already made. For a fair score, label a few frames by hand (`--review`).

## Files

| File | Runs where | Does |
|---|---|---|
| `drive_watch.py` | GitHub | Lists and downloads clips from Drive, read-only |
| `run_pipeline.py` | GitHub | The watcher: new clips? start Kaggle, wait, publish |
| `kaggle_train.py` | Kaggle | Runs the real training (`auto_train.py`) on the GPU |
| `.github/workflows/auto-train.yml` | GitHub | The schedule and the "Run workflow" button |

## One-time setup (all in a browser)

**1. Kaggle** (free)
1. Make an account at kaggle.com and **verify your phone** (Kaggle needs this before it gives a GPU or internet in notebooks).
2. Profile ▸ **Settings ▸ API ▸ Create New Token**. It downloads `kaggle.json` holding your username and key.

**2. Google service account** (free)
1. In the same Google Cloud project you used for sign-in (or a new one): **APIs & Services ▸ Library ▸ Google Drive API** is already enabled.
2. **IAM & Admin ▸ Service Accounts ▸ Create service account**, named `skynode-reader`. No roles needed.
3. Open it ▸ **Keys ▸ Add key ▸ Create new key ▸ JSON**. A file downloads. Treat it like a password.
4. Copy the service account's e-mail address (`skynode-reader@…iam.gserviceaccount.com`).
5. In Drive, **share with that e-mail as Viewer**: your `phone_videos` folder, your `skynode_phone_uploads` folder if you use the phone page, and the starting-model file (`drone_v3/weights/best.pt`). Nothing else.

**3. GitHub** (repository ▸ Settings ▸ Secrets and variables ▸ Actions)

*Secrets* (never paste these into a chat):

| Name | Value |
|---|---|
| `GOOGLE_SERVICE_ACCOUNT_JSON` | the whole text of the downloaded JSON key file |
| `KAGGLE_USERNAME` | `username` from `kaggle.json` |
| `KAGGLE_KEY` | `key` from `kaggle.json` |

*Variables*:

| Name | Value |
|---|---|
| `DRIVE_CLIP_FOLDER_IDS` | the Drive folder ids, comma separated (the id is the end of the folder's address) |
| `DRIVE_START_WEIGHTS_FILE_ID` | the id of `best.pt`, used for the very first run |
| `AUTO_TRAIN_ENABLED` | leave unset until a real run by hand works, then `true` |

## Trying it

1. **Actions ▸ Auto train ▸ Run workflow** with the *train_for_real* box left empty. It lists your Drive clips and says which are new (the log says `MODE: LOOK ONLY`). Nothing is copied or started, so it takes about 15 seconds.
2. Run it again with *train_for_real* **ticked** to do one real run by hand (the log says `MODE: REAL RUN`). Watch the log: Kaggle can take a while to start, and a real run lasts an hour or more.
3. When you're happy, set `AUTO_TRAIN_ENABLED` to `true`. After that it checks every 30 minutes by itself. (Scheduled runs only start once this workflow is on the default branch.)

## Good to know

- **Clips are read from the folders directly, not from subfolders** (as `auto_train.py` does). A clip is remembered by its file name.
- **A failed run pauses retries for a day**, so a broken setup can't burn your GPU allowance. To retry sooner, delete `last_failure.json` from the `training-state` release.
- **Kaggle's free GPU has a weekly allowance** and can queue. Check Kaggle for the current numbers.
- **Where things are kept:** `training-state` release (which clips are used), `current-model` release (the weights the next run starts from), and one `model-<date>` pre-release per run with the `.onnx` and a `report.json`.
- **Cost:** nothing. If a free tier changes, this is the part to revisit.

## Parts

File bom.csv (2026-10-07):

part | quantity | purpose | est_cost_usd | link
Raspberry Pi Pico WH | 1 | Servo controller + Wi-Fi link (already owned) | 0.00 | https://www.raspberrypi.com/products/raspberry-pi-pico/
Breadboard | 1 | Power rails and signal wiring (already owned) | 0.00
SG90 micro servo (or SG92R) | 2 | Pan and tilt axes | 11.90 | https://www.adafruit.com/product/169
SG90 pan-tilt bracket (or print hardware/pantilt.scad) | 1 | Holds both servos and the camera | 8.95 | https://www.adafruit.com/product/1968
1080p USB webcam | 1 | The camera that watches the sky | 70.00 | https://www.logitech.com/en-us/shop/p/c920s-pro-hd-webcam
5V 2A USB power supply | 1 | Dedicated servo power | 7.95 | https://www.adafruit.com/product/1994
USB breakout board | 1 | Brings the supply's 5V and GND onto the breadboard rails | 1.50 | https://www.adafruit.com/product/1833
470-1000uF 16V+ electrolytic capacitor | 1 | Absorbs servo current spikes across the servo power rails | 0.95 | https://www.sparkfun.com/electrolytic-decoupling-capacitors-1000uf-25v.html
Jumper wires (male/male) | 1 | Breadboard and servo connections | 3.95 | https://www.adafruit.com/product/758
M2/M3 screw assortment | 1 | Servo tabs and horns (M2) and tilt pivot + base mounting (M3) | 8.00
Computer that runs the model (laptop now / Raspberry Pi 4 later) | 1 | Runs detection and tracking (NOT included in the 113.20 total)

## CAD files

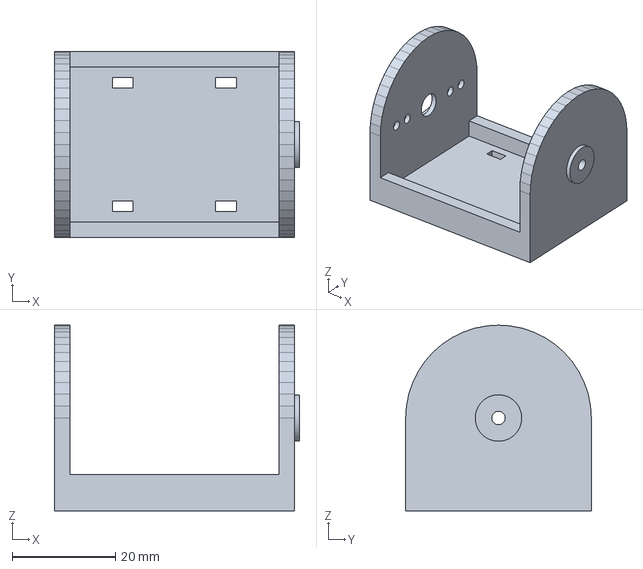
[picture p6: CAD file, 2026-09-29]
hardware/pantilt_camera_arm.step
47.5 x 36.0 x 36.0 mm

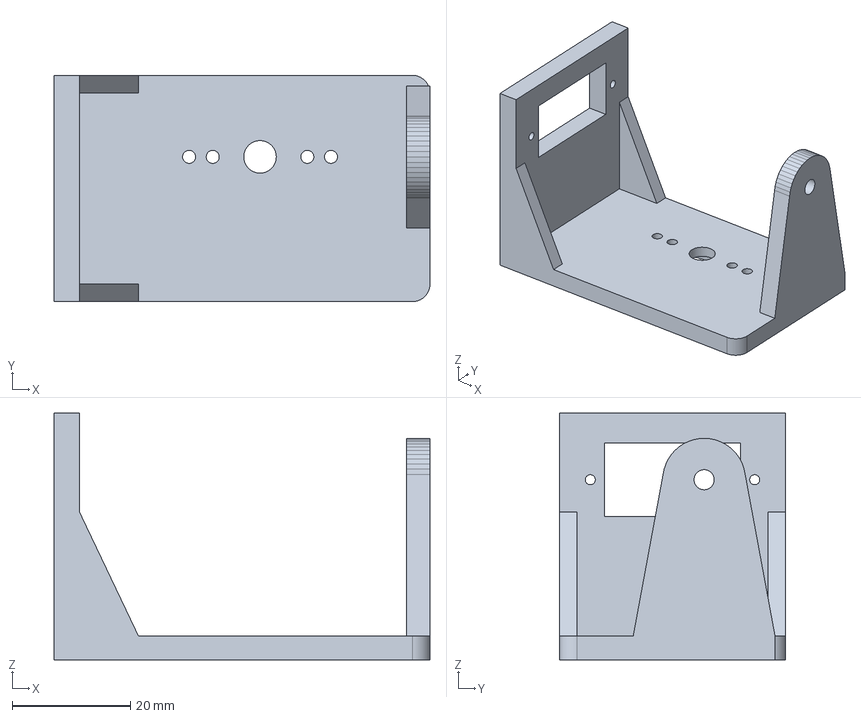
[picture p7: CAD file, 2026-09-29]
hardware/pantilt_yoke.step
63.6 x 38.3 x 41.7 mm

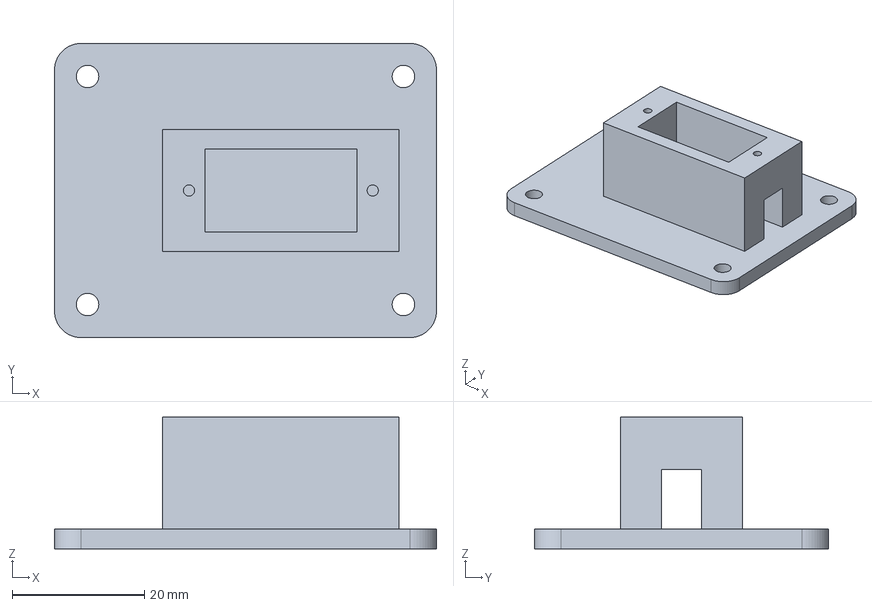
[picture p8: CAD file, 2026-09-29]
hardware/pantilt_base.step
57.8 x 44.5 x 19.9 mm

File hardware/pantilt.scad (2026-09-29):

// pantilt.scad — parametric two-axis pan-tilt mount for SG90 servos + a small USB webcam.
//
// Three printed parts (a two-axis mount needs three links: fixed, panning, tilting):
//   base        holds the pan servo, shaft up; screws down to a board
//   yoke        sits on the pan servo's horn; holds the tilt servo and the pivot
//   camera_arm  cradle for the webcam; hangs on the tilt horn and an M3 pivot
//
// Export one part from the command line:
//   openscad -D 'part="base"'       -o pantilt_base.stl       pantilt.scad
//   openscad -D 'part="yoke"'       -o pantilt_yoke.stl       pantilt.scad
//   openscad -D 'part="camera_arm"' -o pantilt_camera_arm.stl pantilt.scad
// part="assembly" (the default) shows everything put together, for previews.
//
// Print: PLA or PETG, 0.2 mm layers, 3 walls, 25-40 % infill, no supports.
// Each part is exported lying on its flat side. The yoke's servo window is
// a ~23 mm bridge, which most printers handle without supports.
//
// All sizes in mm. MEASURE YOUR SERVO: SG90 clones vary by a few tenths.

part = "assembly";          // "assembly" | "base" | "yoke" | "camera_arm"
pan_angle  = 30;            // assembly preview only
tilt_angle = 35;            // assembly preview only

// ---------- SG90 servo ----------
servo_l = 22.5;             // body length (along the mounting tabs)
servo_w = 12.0;             // body width
servo_h = 22.7;             // body height, bottom to top of case (without the gear boss)
tab_span = 32.3;            // length across both mounting tabs
tab_t = 2.5;                // tab thickness
tab_z = 15.9;               // servo bottom to the UNDERSIDE of the tabs
tab_hole_spacing = 27.8;    // center-to-center of the two tab screw holes
shaft_offset = 5.9;         // output shaft axis, measured from the near end of the body
horn_seat_z = 30.0;         // servo bottom to the underside of the fitted horn's arm

// ---------- Standard SG90 double-arm horn ----------
horn_len = 32.0;            // tip to tip
horn_hub_d = 7.4;           // arm width at the hub
horn_tip_d = 4.2;           // arm width at the tips
horn_t = 1.6;               // arm thickness
horn_hole_r = [8, 12];      // radii of screw holes that fix the horn to the part
horn_screw_d = 2.2;         // clearance for M2 self-tapping screws into the horn

// ---------- Webcam ----------
cam_w = 40;                 // across (side to side)
cam_h = 30;                 // tall
cam_d = 30;                 // deep (front to back, lens pointing forward)

// ---------- General ----------
wall = 3.0;                 // wall / plate thickness
clear = 0.25;               // fit clearance per side
screw_pilot_d = 1.7;        // pilot hole for M2 self-tapping screws (servo tabs)
m3_clear_d = 3.4;
m3_pilot_d = 2.6;           // M3 screw self-tapping into plastic
cable_slot_w = 6;
cable_slot_h = 8;           // above the servo bottom
floor_gap = 1.0;            // air under the pan servo
pivot_gap = 1.5;            // camera arm to the pivot upright (use a washer)

$fn = 48;
eps = 0.01;

// ---------- Derived ----------
tab_len = (tab_span - servo_l) / 2;
upright_t = servo_h - tab_z - tab_t;           // case top ends flush with the upright's inner face
cheek_x = cam_w / 2 + clear + wall;            // camera arm outer faces at +/- cheek_x
horn_gap = horn_seat_z - tab_z - tab_t - upright_t;   // tilt upright inner face to camera arm
swing_r = max(norm([cam_h / 2 + wall, cam_d / 2 + wall]), horn_len / 2 + 3);
axis_z = swing_r + 2;                          // tilt axis above the yoke plate's top
up_l_x = -cheek_x - horn_gap;                  // left upright inner face (tilt servo side)
up_r_x = cheek_x + pivot_gap;                  // right upright inner face (pivot side)
base_top = wall + floor_gap + tab_z;           // tabs rest here
yoke_z = wall + floor_gap + horn_seat_z;       // yoke plate underside, in the assembly

// =====================================================================
// Shared shapes
// =====================================================================

// 2D outline of the double horn, centered on the shaft, arms along X.
module horn_2d(extra = 0) {
    hull() {
        circle(d = horn_hub_d + 2 * extra);
        for (s = [-1, 1]) translate([s * (horn_len - horn_tip_d) / 2, 0])
            circle(d = horn_tip_d + 2 * extra);
    }
}

// Pocket for the horn on a face (face at z=0, material at z>0): recess,
// screw access hole in the middle, holes for the fixing screws.
module horn_socket(depth_through) {
    translate([0, 0, -eps]) linear_extrude(horn_t + 0.2 + eps) horn_2d(clear);
    translate([0, 0, -eps]) cylinder(d = 5.5, h = depth_through + 2 * eps);
    for (r = horn_hole_r, s = [-1, 1])
        translate([s * r, 0, -eps]) cylinder(d = horn_screw_d, h = depth_through + 2 * eps);
}

module rounded_box(size, r = 3) {
    hull() for (x = [r, size[0] - r], y = [r, size[1] - r])
        translate([x, y, 0]) cylinder(r = r, h = size[2]);
}

// Rough SG90 stand-in for the assembly view (shaft at the origin, pointing +Z).
module sg90_model() {
    color("RoyalBlue", 0.85) {
        translate([-shaft_offset, -servo_w / 2, 0]) cube([servo_l, servo_w, servo_h]);
        translate([-shaft_offset - tab_len, -servo_w / 2, tab_z]) cube([tab_span, servo_w, tab_t]);
        cylinder(d = servo_w, h = servo_h + 4);
    }
    color("White") translate([0, 0, horn_seat_z]) linear_extrude(horn_t) horn_2d();
}

// =====================================================================
// Part 1: base (pan servo, shaft on the Z axis)
// =====================================================================
module base() {
    body_cx = servo_l / 2 - shaft_offset;      // servo body center, relative to the shaft
    in_l = servo_l + 2 * clear;
    in_w = servo_w + 2 * clear;
    box_l = in_l + 2 * (tab_len + 1.5);
    box_w = in_w + 2 * wall;
    plate = [box_l + 22, box_w + 26, wall];
    difference() {
        union() {
            translate([-plate[0] / 2, -plate[1] / 2, 0]) rounded_box(plate, 4);
            translate([body_cx - box_l / 2, -box_w / 2, 0]) cube([box_l, box_w, base_top]);
        }
        // servo pocket
        translate([body_cx - in_l / 2, -in_w / 2, wall]) cube([in_l, in_w, base_top]);
        // tab screw pilot holes
        for (s = [-1, 1]) translate([body_cx + s * tab_hole_spacing / 2, 0, base_top - 10])
            cylinder(d = screw_pilot_d, h = 10 + eps);
        // cable slots, both ends (the lead exits low on one end of the case)
        for (s = [-1, 1]) translate([body_cx + s * (in_l / 2 + tab_len), 0, wall + (floor_gap + cable_slot_h) / 2])
            cube([2 * tab_len + 4, cable_slot_w, floor_gap + cable_slot_h], center = true);
        // M3 mounting holes in the corners
        for (x = [-1, 1], y = [-1, 1]) translate([x * (plate[0] / 2 - 5), y * (plate[1] / 2 - 5), -eps])
            cylinder(d = m3_clear_d, h = wall + 2 * eps);
    }
}

// =====================================================================
// Part 2: yoke (pan axis = Z, plate underside at z=0; tilt axis along X at y=0)
// =====================================================================
module yoke() {
    body_cy = -(servo_l / 2 - shaft_offset);   // tilt servo lies along Y, long end toward the back
    win_l = servo_l + 2 * clear;
    win_w = servo_w + 2 * clear;
    up_l_y0 = body_cy - tab_span / 2 - 3;
    up_l_y1 = body_cy + tab_span / 2 + 3;
    up_h = wall + axis_z + win_w / 2 + 5;
    x0 = up_l_x - upright_t;
    x1 = up_r_x + wall + 1;
    difference() {
        union() {
            // plate
            translate([x0, up_l_y0, 0]) rounded_box([x1 - x0, up_l_y1 - up_l_y0, wall + 1], 3);
            // left upright: holds the tilt servo
            translate([x0, up_l_y0, 0]) cube([upright_t, up_l_y1 - up_l_y0, up_h]);
            // right upright: pivot tower
            hull() {
                translate([up_r_x, -12, 0]) cube([wall + 1, 24, wall + 1]);
                translate([up_r_x, 0, wall + axis_z]) rotate([0, 90, 0]) cylinder(r = 7, h = wall + 1);
            }
            // gussets
            for (y = [up_l_y0, up_l_y1 - wall]) hull() {
                translate([x0, y, 0]) cube([upright_t, wall, up_h * 0.6]);
                translate([x0, y, 0]) cube([upright_t + 10, wall, wall + 1]);
            }
        }
        // pan horn socket in the underside
        horn_socket(wall + 1);
        // tilt servo window + tab screw holes
        translate([x0 - eps, body_cy - win_l / 2, wall + axis_z - win_w / 2])
            cube([upright_t + 2 * eps, win_l, win_w]);
        for (s = [-1, 1]) translate([x0 - eps, body_cy + s * tab_hole_spacing / 2, wall + axis_z])
            rotate([0, 90, 0]) cylinder(d = screw_pilot_d, h = upright_t + 2 * eps);
        // pivot hole
        translate([up_r_x - eps, 0, wall + axis_z]) rotate([0, 90, 0]) cylinder(d = m3_clear_d, h = wall + 2);
    }
}
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

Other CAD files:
hardware/pantilt_base.stl
hardware/pantilt_camera_arm.stl
hardware/pantilt_yoke.stl

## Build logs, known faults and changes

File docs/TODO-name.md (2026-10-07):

# TODO: name decision pending

**Status: open. Do not rename anything yet.**

Outside reviewers pointed out that "Skynode" is already used by unrelated
businesses. That has not been independently checked yet.

To decide:

- [ ] Search trademark databases and the web for "Skynode" in the US and in
      the countries this project could reach (aerospace, defense, drones,
      software).
- [ ] Check that the domain, GitHub, and social handles are still free for
      the alternatives.
- [ ] Decide: keep the name, or pick a new one.
- [ ] If renaming, one pass over the repo, the website (`web/src/content.js`),
      the Netlify project, and the banner/social images.

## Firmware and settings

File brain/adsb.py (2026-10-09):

"""Log which real aircraft are overhead, so sightings can be checked against them.

Free public ADS-B feeds only answer "what is flying near here right now". They keep
no history you can ask for later. So this runs next to the brain and writes down,
every few seconds, each aircraft within range of the camera:

    logs/adsb_log.csv     one row per aircraft per poll (where it was, how high,
                          and where it is in YOUR sky: azimuth and elevation)
    logs/adsb_polls.csv   one row per poll (when, did the feed answer, how many).
                          It tells "no aircraft overhead" apart from "this was not running".

    python -m brain.adsb                       # runs until Ctrl+C
    python -m brain.adsb --once                # one poll, then stop (a quick check)

`python -m brain.adsb_compare` then lines the sightings up with this log.

Your location. The camera's latitude and longitude are needed to work out where an
aircraft is in your sky, and they point at your home. They are NEVER read from
brain/config.toml (this is a public repo). Put them in one of:

    environment:   SKYNODE_LAT, SKYNODE_LON, SKYNODE_ALT_M (altitude is optional)
    file:          brain/location.local.toml   (git ignores it)
                       lat = 40.1234
                       lon = -73.5678
                       alt_m = 12

What the feed learns. The request itself contains a position. To keep your address from
the feed's logs, the request uses your location rounded to 0.01 degree (about 1 km) and a
radius that is 2 km larger than you asked for; the exact distances are worked out here,
on your computer. Use --exact if you don't mind sending the precise position.

Needs nothing but the standard library. A feed error never stops the loop.
"""
import argparse
import csv
import json
import math
import os
import time
import tomllib
import urllib.error
import urllib.request
from dataclasses import dataclass
from datetime import datetime, timezone
from pathlib import Path

REPO = Path(__file__).resolve().parent.parent
LOCATION_FILE = Path(__file__).resolve().parent / "location.local.toml"
DEFAULT_FOLDER = REPO / "logs"
LOG_NAME, POLLS_NAME = "adsb_log.csv", "adsb_polls.csv"

# Both feeds answer the same way (the "readsb" format) and need no account or key.
FEEDS = {
    "adsb.lol": "https://api.adsb.lol/v2/point/{lat}/{lon}/{radius_nm}",
    "airplanes.live": "https://api.airplanes.live/v2/point/{lat}/{lon}/{radius_nm}",
}
USER_AGENT = "skynode-adsb-logger (+https://github.com/bsalsa2/skynode)"
EARTH_RADIUS_M = 6371000.0
KM_PER_NM = 1.852
FT_TO_M = 0.3048
KNOTS_TO_MS = 0.514444
PRIVACY_MARGIN_KM = 2.0     # extra radius asked for when the position is rounded
MIN_INTERVAL_S = 5.0        # be gentle with a free service
LOG_COLUMNS = ("time_iso", "unix", "hex", "callsign", "lat", "lon", "alt_m", "speed_ms",
               "distance_km", "azimuth_deg", "elevation_deg")
POLL_COLUMNS = ("unix", "time_iso", "ok", "aircraft")


@dataclass
class Camera:
    lat: float
    lon: float
    alt_m: float = 0.0


class LocationError(ValueError):
    """The camera's position is missing or unusable (the message says what to do)."""


def load_location(environ=None, path=LOCATION_FILE):
    """The camera position from the environment, else from brain/location.local.toml."""
    environ = os.environ if environ is None else environ
    if environ.get("SKYNODE_LAT") or environ.get("SKYNODE_LON"):
        values = {"lat": environ.get("SKYNODE_LAT"), "lon": environ.get("SKYNODE_LON"),
                  "alt_m": environ.get("SKYNODE_ALT_M", 0)}
        origin = "SKYNODE_LAT / SKYNODE_LON"
    elif Path(path).is_file():
        with open(path, "rb") as handle:
            values = tomllib.load(handle)
        origin = str(path)
    else:
        raise LocationError(
            "No camera location. Set SKYNODE_LAT and SKYNODE_LON, or create "
            f"{LOCATION_FILE.name} next to brain/config.toml containing lat = ... and "
            "lon = ... (git ignores that file). It is never read from config.toml.")
    try:
        camera = Camera(float(values["lat"]), float(values["lon"]), float(values.get("alt_m", 0)))
    except (KeyError, TypeError, ValueError):
        raise LocationError(f"{origin}: lat and lon must be numbers (alt_m is optional).") from None
    if not (-90 <= camera.lat <= 90 and -180 <= camera.lon <= 180):
        raise LocationError(f"{origin}: lat must be -90..90 and lon -180..180.")
    return camera


# ---- Geometry -------------------------------------------------------------------

def haversine_m(lat1, lon1, lat2, lon2):
    """Ground distance between two points, in metres."""
    p1, p2 = math.radians(lat1), math.radians(lat2)
    a = (math.sin((p2 - p1) / 2) ** 2
         + math.cos(p1) * math.cos(p2) * math.sin(math.radians(lon2 - lon1) / 2) ** 2)
    return 2 * EARTH_RADIUS_M * math.asin(min(1.0, math.sqrt(a)))


def bearing_deg(lat1, lon1, lat2, lon2):
    """Compass direction from point 1 to point 2: 0 = north, 90 = east."""
    p1, p2 = math.radians(lat1), math.radians(lat2)
    dlon = math.radians(lon2 - lon1)
    y = math.sin(dlon) * math.cos(p2)
    x = math.cos(p1) * math.sin(p2) - math.sin(p1) * math.cos(p2) * math.cos(dlon)
    return math.degrees(math.atan2(y, x)) % 360


def elevation_deg(ground_m, height_m):
    """Angle above the horizon of something `height_m` higher than the camera.

    Ignores the curve of the Earth, which is below 1 degree inside 40 km.
    """
    return math.degrees(math.atan2(height_m, ground_m)) if ground_m > 0 else 90.0


# ---- Reading the feed -------------------------------------------------------------

def number(value):
    """A finite float, or None for anything else (the feeds send "ground" and nulls)."""
    if isinstance(value, bool) or not isinstance(value, (int, float)):
        return None
    return float(value) if math.isfinite(value) else None


def parse_aircraft(payload, camera, max_km=None):
    """Aircraft rows (dicts keyed by LOG_COLUMNS minus time) from one feed answer.

    Skips aircraft with no position, no usable altitude, or on the ground, and (if
    max_km is given) those farther than that from the camera. A damaged entry is
    skipped, never fatal.
    """
    rows = []
    entries = payload.get("ac") if isinstance(payload, dict) else None
    for entry in entries if isinstance(entries, list) else []:
        if not isinstance(entry, dict):
            continue
        lat, lon = number(entry.get("lat")), number(entry.get("lon"))
        altitude_ft = number(entry.get("alt_geom"))
        if altitude_ft is None:
            altitude_ft = number(entry.get("alt_baro"))     # "ground" is a string: skipped
        if lat is None or lon is None or altitude_ft is None:
            continue
        if not (-90 <= lat <= 90 and -180 <= lon <= 180):
            continue
        ground_m = haversine_m(camera.lat, camera.lon, lat, lon)
        if max_km is not None and ground_m > max_km * 1000:
            continue
        alt_m = altitude_ft * FT_TO_M
        speed = number(entry.get("gs"))
        rows.append({
            "hex": str(entry.get("hex", "")).strip().lower(),
            "callsign": str(entry.get("flight", "")).strip(),
            "lat": round(lat, 5), "lon": round(lon, 5), "alt_m": round(alt_m),
            "speed_ms": "" if speed is None else round(speed * KNOTS_TO_MS, 1),
            "distance_km": round(ground_m / 1000, 2),
            "azimuth_deg": round(bearing_deg(camera.lat, camera.lon, lat, lon), 1),
            "elevation_deg": round(elevation_deg(ground_m, alt_m - camera.alt_m), 1),
        })
    return rows


def feed_url(feed, camera, radius_km, exact=False):
    """The request address. Unless `exact`, the position is rounded to ~1 km (see top)."""
    if exact:
        lat, lon, margin = camera.lat, camera.lon, 0.0
    else:
        lat, lon, margin = round(camera.lat, 2), round(camera.lon, 2), PRIVACY_MARGIN_KM
    radius_nm = max(1, math.ceil((radius_km + margin) / KM_PER_NM))
    return FEEDS[feed].format(lat=f"{lat:.5f}", lon=f"{lon:.5f}", radius_nm=min(radius_nm, 250))


def fetch_json(url, timeout=10):
    request = urllib.request.Request(url, headers={"User-Agent": USER_AGENT})
    with urllib.request.urlopen(request, timeout=timeout) as response:
        return json.loads(response.read(5_000_000))


# ---- Writing the log ----------------------------------------------------------------

def iso_utc(unix):
    return datetime.fromtimestamp(unix, timezone.utc).isoformat(timespec="seconds")


def append_rows(path, columns, rows):
    path = Path(path)
    path.parent.mkdir(parents=True, exist_ok=True)
    fresh = not path.is_file() or path.stat().st_size == 0
    with open(path, "a", newline="", encoding="utf-8") as handle:
        writer = csv.DictWriter(handle, fieldnames=columns)
        if fresh:
            writer.writeheader()
        writer.writerows(rows)


def poll_once(camera, folder, feed="adsb.lol", radius_km=25.0, exact=False,
              fetch=fetch_json, now=None):
    """Ask the feed once and log the answer. Returns the number of aircraft logged, or None
    if the feed could not be read (that is logged too, as ok = 0)."""
    now = time.time() if now is None else now
    folder = Path(folder)
    stamp = {"unix": round(now, 1), "time_iso": iso_utc(now)}
    try:
        payload = fetch(feed_url(feed, camera, radius_km, exact))
        rows = parse_aircraft(payload, camera, max_km=radius_km)
    except (OSError, ValueError, urllib.error.URLError) as error:   # includes JSON errors, timeouts
        append_rows(folder / POLLS_NAME, POLL_COLUMNS, [{**stamp, "ok": 0, "aircraft": 0}])
        print(f"WARN ADS-B feed: {error}")
        return None
    append_rows(folder / LOG_NAME, LOG_COLUMNS, [{**stamp, **row} for row in rows])
    append_rows(folder / POLLS_NAME, POLL_COLUMNS, [{**stamp, "ok": 1, "aircraft": len(rows)}])
    return len(rows)


def main(argv=None):
    parser = argparse.ArgumentParser(description="Log the aircraft overhead to logs/adsb_log.csv.")
    parser.add_argument("--feed", choices=sorted(FEEDS), default="adsb.lol")
    parser.add_argument("--radius-km", type=float, default=25.0, help="how far out to log")
    parser.add_argument("--interval", type=float, default=10.0, help="seconds between polls")
    parser.add_argument("--folder", type=Path, default=DEFAULT_FOLDER, help="where the logs go")
    parser.add_argument("--exact", action="store_true",
                        help="send your precise position to the feed (default: rounded to ~1 km)")
    parser.add_argument("--once", action="store_true", help="poll one time, then stop")
    args = parser.parse_args(argv)

    try:
        camera = load_location()
    except LocationError as error:
        raise SystemExit(str(error)) from None
    interval = max(args.interval, MIN_INTERVAL_S)
    print(f"ADS-B logger: {args.feed}, within {args.radius_km:g} km, every {interval:g} s, "
          f"into {args.folder}. Ctrl+C to stop.")
    try:
        while True:
            count = poll_once(camera, args.folder, args.feed, args.radius_km, args.exact)
            if args.once:
                print("feed unreachable" if count is None else f"{count} aircraft in range")
                return 0 if count is not None else 1
            time.sleep(interval)
    except KeyboardInterrupt:
        print("\nstopped")
    return 0


if __name__ == "__main__":
    raise SystemExit(main())

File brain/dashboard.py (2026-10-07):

"""The live dashboard: a small web server inside the brain, for your browser.

Open http://localhost:8080/ while the brain runs and you see what the camera
sees, the box around whatever it is tracking, and the sighting log. It is all
served from this computer: no internet, no cloud, no account.

What the browser can ask for (GET only: this server never changes anything):

    /                     the page itself (brain/dashboard/index.html)
    /assets/<file>        its CSS, JavaScript, fonts and icons (from brain/dashboard/)
    /api/state            what the camera sees right now, plus node status
    /api/stats            sighting counts per hour, from the logger
    /api/sightings        the sighting log, newest first, one page at a time
    /api/sightings.csv    the same log as a spreadsheet file (e.g. to compare with ADS-B)
    /api/config           the brain's settings, read-only
    /snapshots/<id>.jpg   the photo saved with a sighting
    /snapshot.jpg         one still picture from the live camera
    /stream.mjpg          the live camera as "MJPEG": an endless series of JPEG
                          pictures. Browsers show it in a plain <img>, no video player.

How it fits into the brain:
- The main loop calls publish() once per frame. publish() has to be quick, so
  it only copies a few numbers and, now and then, a shrunk COPY of the frame.
- The web server answers each request on its own thread, so a slow browser
  can never slow down tracking. Turning pictures into JPEGs happens on those
  threads too, never in the main loop.
- Data shared between the threads sits behind one lock. A Condition (a lock
  that threads can wait on) wakes the stream threads when a new picture
  arrives, so they sleep in between instead of checking over and over.

Safety: by default only this computer can open the page (host 127.0.0.1).
With host = "0.0.0.0" anyone on your Wi-Fi can, and there is no password.
Files only ever come from brain/dashboard/ and the snapshots folder: names
with "..", hidden files and odd characters are refused. And the page must be
opened by an address like localhost, 192.168.1.20 or raspberrypi.local, not
by a web site's name: see host_allowed() for the trick that this blocks.
Other web sites can't put the camera or the snapshots on their pages either:
see fetch_allowed().

OpenCV is only imported to make pictures, so without it everything except the
live picture still works (and the tests run without it).
"""
import csv
import io
import ipaddress
import json
import math
import numbers
import os
import re
import select
import socket
import socketserver
import sys
import threading
import time
from datetime import datetime, timezone
from http.server import BaseHTTPRequestHandler, ThreadingHTTPServer
from pathlib import Path, PurePosixPath
from urllib.parse import parse_qsl, unquote

MAX_VIEWERS = 4                 # live streams at once (each costs JPEG work on this computer)
MAX_DETECTIONS = 20             # detections per frame sent to the page
ONLINE_WITHIN_S = 3.0           # "online" = a frame arrived at least this recently
GAP_S = 1.0                     # a pause between frames longer than this = "wasn't watching"
STILL_EVERY_S = 1.0             # with no stream viewers, keep a fresh still about this often
STREAM_WAIT_S = 2.0             # stream threads wake at least this often to check for shutdown
STREAM_QUALITY = 75             # JPEG quality of the live picture (snapshots use 85)
MAX_STATS_HOURS = 168           # /api/stats looks back at most a week
MAX_SIGHTINGS_HOURS = 87600     # /api/sightings: 10 years, just to keep the numbers sane
MAX_LIMIT = 200                 # sightings per page
CSV_LIMIT = 10000               # rows in one CSV export
MAX_QUERY_FIELDS = 20           # "?a=1&b=2..." pairs accepted in one request

CATEGORIES = ("drone", "aircraft", "other", "clear")
KINDS = ("sighting", "check")
DRONE_CLASSES = ("drone",)                                  # used when there's no logger
AIRCRAFT_CLASSES = ("airplane", "aircraft", "helicopter")

# The only file types /assets/ serves. Anything else is a 404.
ASSET_TYPES = {
    ".css": "text/css; charset=utf-8",
    ".js": "text/javascript; charset=utf-8",
    ".woff2": "font/woff2",
    ".svg": "image/svg+xml",
    ".png": "image/png",
    ".txt": "text/plain; charset=utf-8",
}
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

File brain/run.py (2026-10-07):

"""Skynode brain: webcam -> YOLO (ONNX) -> tracker -> controller -> Pico.

Run from the repo root:
    python -m brain.run                        # settings from brain/config.toml
    python -m brain.run --link wifi            # override the link type
    python -m brain.run --source planes.mp4    # a video file instead of the webcam
    python -m brain.run --port 8081            # the dashboard on another port
    python -m brain.run --no-dashboard         # no web dashboard this time

While it runs, open the live dashboard in a browser: http://localhost:8080/
Every sighting is logged to logs/ (see [logger] in brain/config.toml).

Quit with q or Esc in the preview window, or Ctrl+C in the terminal.
"""
import argparse
import dataclasses
import os
import time
from pathlib import Path
from urllib.parse import urlsplit

import cv2

from brain.config import load_config
from brain.controller import PanTiltController
from brain.dashboard import Dashboard
from brain.detector import Detector
from brain.link import NullLink, open_link, read_pico_state
from brain.logger import SightingLogger
from brain.overlay import draw_overlay
from brain.tracker import Tracker

DEFAULT_CONFIG = Path(__file__).with_name("config.toml")
REPO = Path(__file__).resolve().parent.parent


def parse_args(argv=None):
    parser = argparse.ArgumentParser(description="Skynode brain: detect, track, point the camera.")
    parser.add_argument("--config", type=Path, default=DEFAULT_CONFIG,
                        help="settings file (default: brain/config.toml)")
    parser.add_argument("--link", choices=["wifi", "usb", "none"], help="override [link] type")
    parser.add_argument("--source", help="webcam number or video file (overrides [camera] source)")
    parser.add_argument("--model", help="path to an .onnx model (overrides [model] path)")
    parser.add_argument("--headless", action="store_true", help="no preview window")
    parser.add_argument("--loop", action="store_true",
                        help="when a video file ends, start it again (for demos)")
    parser.add_argument("--port", type=port_number,
                        help="dashboard port (overrides [dashboard] port, normally 8080)")
    parser.add_argument("--no-dashboard", action="store_true",
                        help="don't start the live web dashboard")
    return parser.parse_args(argv)


def port_number(text):
    """--port must be a whole number from 1 to 65535 (that's all the ports there are)."""
    try:
        port = int(text)
    except ValueError:
        port = 0
    if not 1 <= port <= 65535:
        raise argparse.ArgumentTypeError(f"{text!r} isn't a port number (1-65535)")
    return port


def main(argv=None):
    args = parse_args(argv)
    cfg = load_config(args.config)
    if args.link:
        cfg.link.type = args.link
    if args.source is not None:
        cfg.camera.source = int(args.source) if args.source.isdigit() else args.source
    if args.model:
        cfg.model.path = args.model
    if args.headless:
        cfg.display.show = False
    if args.loop:
        cfg.camera.loop = True
    if args.port is not None:
        cfg.dashboard.port = args.port
    if args.no_dashboard:
        cfg.dashboard.enabled = False

    if not Path(cfg.model.path).exists():
        raise SystemExit(f"Model not found: {cfg.model.path}\n"
                         "Export one first: see 'Get a model' in brain/README.md.")
    detector = Detector(cfg.model.path, cfg.model.min_confidence, cfg.model.iou_threshold)
    check_target_classes(cfg.model.target_classes, detector.class_names)
    print(f"Model: {cfg.model.path} (tracking {', '.join(cfg.model.target_classes)})")

    tracker = Tracker(cfg.model.target_classes, cfg.tracker.max_missed_frames, cfg.tracker.max_jump)
    c = cfg.control
    controller = PanTiltController(cfg.camera.hfov_deg, c.gain, c.deadband_deg, c.max_step_deg,
                                   c.pan_sign, c.tilt_sign)

    link = open_link(cfg.link.type, cfg.link.serial_port, cfg.link.wifi_host, cfg.link.wifi_port)
    print(f"Link: {link.description}")
    sync_with_pico(link, controller)

    logger = make_logger(cfg)
    camera = open_camera(cfg.camera)
    dashboard = make_dashboard(cfg, logger, link)
    try:
        run_loop(camera, detector, tracker, controller, link, cfg, logger=logger,
                 dashboard=dashboard)
    except KeyboardInterrupt:
        pass
    finally:
        camera.release()
        link.close()
        if logger is not None:
            report(logger.close())      # a sighting still going on gets logged too
        if dashboard is not None:
            dashboard.stop()
        if cfg.display.show:
            cv2.destroyAllWindows()     # (headless OpenCV has no windows, and errors here)
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

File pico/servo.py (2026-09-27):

# servo.py — driver for one hobby servo (SG90 or similar) on a Raspberry Pi Pico.
#
# How a hobby servo is controlled:
#   Every 20 ms (50 times a second) the Pico sends a short HIGH pulse.
#   The pulse WIDTH sets the angle: roughly 500 us = 0 deg, 2400 us = 180 deg.
#   Every servo is slightly different, so the two end widths (min_us, max_us)
#   are calibratable instead of hard-coded.
#
# Smooth motion:
#   We never jump straight to a new angle. set_target() only records where we
#   WANT to go; update() is called every loop tick and moves the servo a small
#   step toward the target, capped at `speed` degrees per second. This keeps
#   camera motion smooth and avoids big current spikes on the 5 V rail.

from machine import Pin, PWM

FRAME_HZ = 50                  # standard servo frame rate: one pulse every 20 ms
PULSE_MIN_US = 400             # hard safety bounds for any hobby servo pulse;
PULSE_MAX_US = 2600            # calibration values must fall inside these


class Servo:
    def __init__(self, pin, min_us=500, max_us=2400, min_deg=0, max_deg=180, start_deg=90):
        check_pulse_range(min_us, max_us)
        check_angle_range(min_deg, max_deg)
        self.pin = pin
        self.min_us = min_us          # pulse width that points the horn at 0 deg
        self.max_us = max_us          # pulse width that points the horn at 180 deg
        self.min_deg = min_deg        # software angle limits (protect the bracket/cables)
        self.max_deg = max_deg
        self.angle = self.clamp(start_deg)   # where we are right now
        self.target = self.angle             # where we are heading
        self.active = True                   # False = no pulses, servo goes limp

        self.pwm = PWM(Pin(pin))
        self.pwm.freq(FRAME_HZ)
        self.write_us(self.angle_to_us(self.angle))

    # ---- conversions -------------------------------------------------------

    def clamp(self, deg):
        """Force an angle inside this servo's limits."""
        return min(max(deg, self.min_deg), self.max_deg)

    def angle_to_us(self, deg):
        """Map 0..180 deg linearly onto min_us..max_us."""
        return self.min_us + (self.max_us - self.min_us) * deg / 180

    # ---- commands ----------------------------------------------------------

    def set_target(self, deg):
        """Ask the servo to move to `deg`. Out-of-range values are clamped, not rejected."""
        self.target = self.clamp(deg)
        if not self.active:
            # Wake up from relax(): start pulsing again at the last known angle.
            self.active = True
            self.write_us(self.angle_to_us(self.angle))

    def calibrate(self, min_us, max_us):
        """Set the pulse widths for 0 and 180 deg, and apply them right away."""
        check_pulse_range(min_us, max_us)
        self.min_us = min_us
        self.max_us = max_us
        if self.active:
            self.write_us(self.angle_to_us(self.angle))

    def set_limits(self, min_deg, max_deg):
        """Set the allowed angle range. If the servo is outside it, update() will ease it back in."""
        check_angle_range(min_deg, max_deg)
        self.min_deg = min_deg
        self.max_deg = max_deg
        self.target = self.clamp(self.target)

    def relax(self):
        """Stop sending pulses. The servo stops holding and can be turned by hand."""
        self.pwm.duty_ns(0)
        self.active = False

    def write_us(self, us):
        """Send a raw pulse width in microseconds (the hardware takes nanoseconds)."""
        self.pwm.duty_ns(int(us * 1000))

    def raw_us(self, us):
        """Calibration helper: send an exact pulse width, bypassing angles and limits."""
        if not PULSE_MIN_US <= us <= PULSE_MAX_US:
            raise ValueError(f"pulse must be {PULSE_MIN_US}-{PULSE_MAX_US} us")
        self.active = True
        self.write_us(us)

    # ---- motion ------------------------------------------------------------

    def update(self, dt, speed):
        """Step toward the target. Call every loop tick.

        dt    -- seconds since the last call
        speed -- maximum speed in degrees per second
        """
        if not self.active or self.angle == self.target:
            return
        max_step = speed * dt
        error = self.target - self.angle
        if abs(error) <= max_step:
            self.angle = self.target          # close enough: land exactly on target
        elif error > 0:
            self.angle += max_step
        else:
            self.angle -= max_step
        self.write_us(self.angle_to_us(self.angle))


def check_pulse_range(min_us, max_us):
    if not PULSE_MIN_US <= min_us < max_us <= PULSE_MAX_US:
        raise ValueError(f"need {PULSE_MIN_US} <= min_us < max_us <= {PULSE_MAX_US}")


def check_angle_range(min_deg, max_deg):
    if not 0 <= min_deg < max_deg <= 180:
        raise ValueError("need 0 <= min_deg < max_deg <= 180")

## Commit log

2026-09-27 Set up repo structure, README, and gitignore rules
    - Add pico/, brain/, docs/, hardware/ folders, each with a short README
    - Ignore model weights (*.onnx, *.pt), datasets/ and logs/
    - README: overview, how it works, wiring, power notes, roadmap
    Claude-Session: https://claude.ai/code/session_01AEg9NLpkLS4jpPeCABdiho
2026-09-27 pico: add Servo driver with calibration, limits, and smooth motion
    - Pulse widths for 0/180 deg are calibratable (min_us/max_us)
    - Software angle limits; out-of-range targets are clamped
    - update() slews toward the target at a capped deg/s, so no jumps
    - relax() stops pulses; raw_us() helps find a servo's end stops
    - tests/fake_machine.py stubs MicroPython's machine module so the
    driver can be unit-tested on a laptop
    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
2026-09-27 pico: add serial command parser
    Plain-text protocol, one command per line: "P90 T45" moves, plus HOME,
    SPEED, ?, CFG, CAL, LIM, RAW, OFF, SAVE. parse() checks syntax only and
    raises ValueError with a short message the Pico can echo back as ERR.
    No hardware imports, so the brain can reuse it.
    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
    [protocol.py, test_protocol.py]
2026-09-27 pico: add PanTilt controller, serial main loop, and firmware guide
    - pantilt.py runs protocol commands on the two servos and saves
    calibration to config.json so it survives power cycles
    - main.py polls USB serial without blocking and steps the servos at
    50 Hz; moves are silent so the brain can stream them
    - pico/README.md: flashing, Thonny/mpremote upload, calibration
    walkthrough, protocol reference, troubleshooting
    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
2026-09-27 pico: add optional Wi-Fi link (UDP) alongside USB serial
    - wifi.py joins the network from wifi_secrets.py, listens on UDP 5005
    for the same commands, and replies to the sender; power saving is off
    to keep latency low, and it rejoins every 15 s if the link drops
    - main.py serves USB and Wi-Fi in the same loop; any Wi-Fi failure
    leaves USB working
    - wifi_secrets.py is gitignored; wifi_secrets_example.py is the template
    - Tests simulate the radio and socket: replies, multi-line datagrams,
    link drop + retry, and USB-only when there are no secrets
    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
    [main.py, test_main.py, wifi.py]
2026-09-27 brain: add single-target tracker and proportional pan-tilt controller
    - Tracker filters to target classes, locks onto the most confident one,
    then follows the nearest match; drops the lock after N missed frames
    - Controller converts pixel offset to degrees with a pinhole camera
    model, corrects a fixed share (gain) per frame, with deadband, step
    cap, per-axis direction signs, and the Pico's own limits and home
    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
    [controller.py, test_brain_tracking.py, tracker.py]
2026-09-27 brain: add Wi-Fi/USB links, TOML config, and the main tracking loop
    - link.py: UdpLink (broadcast auto-discovery or fixed host), SerialLink
    (finds the Pico by USB vendor ID), and NullLink for detection-only runs
    - config.toml: model path, target classes, camera, control gains, link
    type; typos are errors; paths are relative to the config file
    - run.py: webcam or video -> detect -> track -> control -> send, syncs
    limits and position from the Pico first, preview window or headless
    - Tests run the brain's UDP link against the real Pico command code
    - README and brain/README: setup, model export, aiming test, swapping
    in a custom model, troubleshooting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
    [config.py, link.py, overlay.py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]
2026-09-29 Add README images, bill of materials, and pan-tilt design files
    - docs/skynode_banner.jpg banner at the top of the README
    - docs/wiring.svg: Pico WH, pan (GP0) and tilt (GP1) SG90s, 5 V 2 A
    supply via USB breakout, 470-1000 uF capacitor, common ground
    - Model training section embedding docs/results.png (image file itself
    still to be added)
    - bom.csv plus a README BOM table with total; blank links where no
    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
    [bom.csv, pantilt.scad, pantilt_base.stl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]
2026-09-29 hardware: rebuild pan-tilt parts in CadQuery with STEP + STL per part
    - hardware/pantilt.py is the new source of truth: same parameters and
    geometry as pantilt.scad (verified: identical size and volume, 100%
    overlap for every part)
    - Exports pantilt_{base,yoke,camera_arm}.step and matching .stl files
    - New docs/pantilt_parts.png, re-rendered docs/pantilt_render.png
    - hardware/README: CadQuery is the source of truth, SCAD kept for
    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
    [pantilt_base.step, pantilt_base.stl, pantilt_camera_arm.step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]
2026-09-29 Mark STEP and STL files as generated for GitHub
    Collapses the model files in PR diffs and excludes them from language
    stats. No history rewrite.
    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
2026-10-04 web: add scroll story, nav, and micro-interactions
    GSAP ScrollTrigger pinning and reveals, self-drawing roadmap line,
    magnetic buttons, tilt + sheen cards, lazy 3D loading.
    Claude-Session: https://claude.ai/code/session_01Y7MAwUUTGrKmFAUaXkHR7z
2026-10-04 web: add Three.js hero scene
    Glass sensor orb, orbiting aircraft, amber tracking reticle and
    starfield. Pauses when hidden or scrolled away; adaptive pixel ratio.
    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
2026-10-04 web: tune hero scene and phone layout
    Add inner glow so the glass orb reads lit on a transparent canvas,
    tighten the aircraft orbit to stay on screen, ease the scene back
    behind the cards, and fix caption spacing on phones.
    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
2026-10-04 web: skip 3D on software WebGL and fall back when frames stay slow
    Software renderers (SwiftShader, llvmpipe) get the static SVG hero.
    A runtime guard hands back to it if frames stay slow at 1x pixel
    ratio. Below-the-fold reveals start fully hidden so audit tools
    don't read them as low-contrast text.
    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
2026-10-04 web: add live 3D viewer of the pan-tilt mount from the CAD files
    scripts/build-models.mjs packs hardware/*.stl into one 108 KB binary
    (quantized, shared vertices) before every build, so CAD changes reach
    the site automatically. mount.js assembles the parts with the same
    transforms as pantilt.py's assembly(), draws the SG90s as outlines,
    and slews pan/tilt between targets like the servos. Lazy-loaded near
    the viewport, pauses off-screen, drag to turn, static for reduced
    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
2026-10-04 web: add mount panel, footage and results slots, Sunnode card
    - How it works gains the pan-tilt mount panel (part notes from
    hardware/README.md); the hero orb now fades out before it.
    - hero.footage: set a video path and it replaces the concept scene
    (paused with controls for reduced motion). Empty for now.
    - results: an accuracy section that stays hidden until measured
    numbers (with a source) are added. Empty for now.
    - sister: a glass card linking to Sunnode above the footer.
    - ?gl=any forces 3D on software WebGL, for testing.
    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
2026-10-04 ci: validate content.js before every build and on pull requests
    scripts/check-content.mjs catches typos (pointing at the line, with
    the usual causes), missing fields, wrong status labels, broken in-page
    links, footage files that weren't uploaded, results without a source,
    and leftover placeholder text. It runs as prebuild, so Pages, Netlify
    and Vercel all refuse to publish a broken file, and a new Check site
    workflow annotates problems on pull requests. STL changes in hardware/
    now also trigger a rebuild.
    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
2026-10-04 web: let scroll drive the hero fade directly after the first reveal
    The canvas's 1.6s fade-in transition also smoothed every scroll-driven
    opacity change, so the orb lagged over the mount panel on fast
    scrolls. Also frame the mount a little closer and refresh its still.
    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
2026-10-04 web: update README for Netlify, footage, results, mount and checks
    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
2026-10-04 State Phase 1 and the defense-autonomy goal across the page
    Copy in web/src/content.js, as approved:
    - Hero eyebrow: 'PHASE 1: AI SKY TRACKER'.
    - New hero line under the buttons (hero.goal): 'This is Phase 1. The
    long-term goal is autonomy for missile and drone defense and attack
    systems.' Styled as a small amber-ruled note; the content check
    validates it when present.
    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
2026-10-07 Align README and site with the code: status, price, wording, model results
    - Site: replace 'attack' with 'detection and defense' (hero goal,
    roadmap Phases 3 and 4). No 'weapons', 'strike' or 'intercept' left.
    - Price: 'about $113 in new parts, plus a small computer to run the
    model' (BOM total $113.20). README notes what the total excludes.
    - Logging: no logger exists yet, so the site and README now say
    sightings will be logged, not that they are.
    - Roadmap/status: Pico firmware and detection loop marked done (code +
    tests, simulation only). README roadmap and site Status now list the
    same 10 items with the same states.
    - README: 'Results so far' for the v2 model and v3 plan; note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
2026-10-07 Rebrand the website to Liquid Graphite
    Rebuild the landing page from the Claude Design "Landing Page" handoff:
    carbon/smoke/halo palette, Saira + IBM Plex type (self-hosted), liquid
    glass with Chromium-only refraction, and the planet-rim + moon horizon.
    - Hero: CSS horizon and moon on first paint; a lazy canvas adds twinkling
    stars and an aircraft pass with an aircraft-blue lock box. The glass
    readout card's pan/tilt/command follow the lock (labelled concept).
    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
2026-10-07 Add sighting logger and live dashboard (checkpoint)
    Checkpoint of the dashboard build before the review fixes land:
    - brain/logger.py: logs each tracker lock as a sighting (time, duration,
    class, peak confidence, pan/tilt, snapshot JPEG) to logs/, plus
    periodic clear-sky checks; 24 h stats and hourly buckets.
    - brain/dashboard.py: stdlib-only local web server for the dashboard:
    JSON API, MJPEG live stream, snapshots, CSV export. Binds to
    127.0.0.1 by default, with a Host check against DNS rebinding.
    - brain/dashboard/: the Liquid Graphite dashboard UI (Overview,
    Sightings, Nodes, Settings), self-hosted fonts, no external requests.
    - brain/run.py + config: [logger] and [dashboard]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
    [config.py, dashboard.py, logger.py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]
2026-10-07 Apply review fixes to the dashboard (pending final verification)
    Backend/security: share one JPEG encode across stream viewers, refuse
    cross-site requests and add Cross-Origin-Resource-Policy, strip
    credentials from camera URLs shown on the dashboard, survive a corrupt
    (deeply nested) log line, pace the stream to the configured fps.
    UI: measured label placement for boxes, honest chart column heights,
    no stale uptime while offline, real 1.5 px locked box, contrast and
    chip focus fixes, yesterday-aware "last at" notes, focus fallback in
    the detail dialog, brand-shaped legend swatches.
    175 tests pass. Independent verifiers are still re-running the original
    repros; any further changes will fol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
    [dashboard.py, logger.py, run.py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]
2026-10-07 Add Colab training notebook for phone-video datasets
    training/skynode_train.ipynb trains a Skynode detector entirely in Google
    Colab: frames are pulled from phone videos on Drive, pre-labeled with a
    COCO model (planes, birds) and YOLO-World (drones), checked by eye on
    numbered contact sheets, split by whole video so the validation score is
    honest, trained from YOLOv8n with Drive checkpoints (resumable), and
    exported to the ONNX format brain/detector.py reads.
    training/skynode_data.py holds the testable bookkeeping (frame
    extraction, YOLO labels, leak-free split, dataset builder with by-name
    class merging, dataset warnings, contact sheets), with 20 tests.
    The GPU cells have not been run in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
    [test_training_data.py]
2026-10-07 Stage 1: honest claims and positioning from the outside reviews
    - Cost: 'About $113 in new parts for the sensing hardware (camera,
    servos, mount, power), before the computer that runs the model.' Drop
    'instead of tens of thousands'; the price tiles now carry a 'price
    comparison only, not a capability comparison' note. BOM sums to
    $113.20; bom.csv and README list the computer as not included.
    - Hero leads with 'A low-cost visual sensing platform, starting with one
    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
    [bom.csv]
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2026-10-07 Share one set of Liquid Graphite tokens between the site and the dashboard
    brain/dashboard/graphite.css now holds the brand tokens (neutrals, the drone
    coral / aircraft blue / clear green signals, chart marks, glass, type stacks).
    The site imports it from web/src/styles.css and the dashboard loads it as
    /assets/graphite.css, so a colour changes in both. Each keeps only its own
    layout sizes. The site's dev server may read ../brain/dashboard.
    Sample content on the public site is now labelled SAMPLE (hero card, caption,
    sensor view), and the content check fails the build if one of those labels
    loses the word. The NODE-01 tag no longer breaks across lines on phones.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
2026-10-07 Store sightings in SQLite instead of daily JSON Lines files
    logs/skynode.db holds every sighting and sky check (id, time, class,
    confidence, duration, pan/tilt, box, frames, snapshot name); snapshots stay
    as JPEGs in logs/snapshots/. Each record is committed as it is logged. The
    logger's behaviour and public API are unchanged (the dashboard reads the same
    in-memory copy), the database is created on the first write, a file that is
    not a database is moved aside rather than crashing, and rows edited badly are
    skipped and counted. Old sightings-YYYY-MM-DD.jsonl files are imported once,
    then renamed to .jsonl.imported.
    The nine tests that read the old files now read the database, with new tests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
    [logger.py, test_brain_logger.py, test_brain_run_dashboard.py]
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2026-10-07 Add one-command auto-train for new phone clips
    training/auto_train.py finds unused clips in phone_videos, labels them
    with the current model, fine-tunes, and replaces the model only if the
    new one scores at least as well on held-out clips. A manifest in Drive
    records which clips were used. The GPU work imports only when training.
    skynode_auto_train.ipynb runs it in Colab with one cell. Tests cover the
    clip bookkeeping, starting-model choice, safety gate and plan; the
    scoring bias without human review is documented in the code and README.
    Claude-Session: https://claude.ai/code/session_019UmCSzU6uzwqe9JN7UbhpP
    [test_auto_train.py]
2026-10-07 Update README model, roadmap and results; hide personal email
    - Model section: describe the current two-class model (drone, aircraft)
    and v3 as in training, not yet scored. Fix the COCO sentence in How it works.
    - Results: retitled "Results so far". Numbers unchanged (v2, 43 videos).
    - Roadmap: match the agreed status. Nothing has run on real hardware yet.
    - .mcp.json: local developer tool config, now git-ignored and untracked.
    - Website: contact email now comes from web/src/config.js (CONTACT_EMAIL, placeholder).
    Personal address removed from tracked files. Older commits still contain it.
    Claude-Session: https://claude.ai/code/se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
2026-10-09 Fix wrong elevation expectation in the ADS-B parsing test
    CI showed the code was right: an aircraft 8.5 km away at 9.1 km altitude is
    47 degrees up, not above 50.
    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
    [test_brain_adsb.py]
2026-10-09 Auto train: create the Kaggle dataset when it doesn't exist yet
    The first real run uploaded 1.2 GB and then got 403 from 'datasets version',
    because Kaggle answers 403 (not 404) for a dataset that doesn't exist, so the
    create fallback never fired. Check existence first (a cheap status call), and
    let a run started by hand ignore the one-day pause after a failure.
    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
    [test_auto_pipeline.py]
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2026-10-12 Apply Talo brand v6: Charcoal + Bronze + Split
    Retheme the website and live dashboard from the Claude Design handoff:
    - Shared tokens (graphite.css): v6 palette, status colours, glass levels,
    stage, light variant; Michroma / Geist / Geist Mono replace Saira / Plex
    - Split mark, numbered nav, [ LABEL ] section markers, lens + SAMPLE
    sighting-card hero; old planet/moon/sky scene and hero.js removed
    - Dashboard: stage backdrop, rounded glass in place of the range-console
    skin, v6 category colours and shapes
    - New favicon set, OG image, README banner; docs/brand assets
    - Content check now enforces SAMPLE on the card and bans off-brand words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
2026-10-13 Site: status line, "What we've tested", clearer cost, tighter nav
    From the website review:
    - Hero: a RESEARCH PROTOTYPE line under the headline saying what exists
    today (software tested on recorded video and in simulation; hardware
    validation pending).
    - New "What we've tested" section near the top: software tests,
    recorded-video results with their limits beside them, and pending
    hardware tests, linking to the full results.
    - Cost labelled "Estimated sensing-hardware parts cost", with the
    computer exclusion beside the figure in the hero and the stats.
    - Nav: Overview, How it works, Results, Status. The scrolling ticker,
    which repeated the hero facts, is removed (it renders nothin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
2026-10-13 Site: state plainly that VARN is a research prototype
    From the second review:
    - Hero eyebrow "Passive airspace awareness"; subline "Exploring how
    computer vision can help people understand the airspace around them."
    - Status row: Software built · Simulation tested · Hardware pending.
    - How it works: "A research prototype for visual airspace detection",
    and the copy no longer claims real-time drone/aircraft classification
    (the v2 model labels only 14.9% of drone clips correctly).
    - Dashboard caption: "Illustrative interface · Simulation, not live
    hardware" (the content check requires it to say simulation).
    Claude-Session: htt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
2026-10-13 Revert the mockup homepage; back to the pre-mockup site (20b328f)
    Reverts 11178fc (rebuild to the mockup) and 9fe2c71 (research-prototype
    copy). The site returns to the Varn-branded version with the review
    fixes, the hero tracking line and the radar plot.
    Claude-Session: https://claude.ai/code/session_01EckdqzKE6Qy7EWqWc5GA8C
